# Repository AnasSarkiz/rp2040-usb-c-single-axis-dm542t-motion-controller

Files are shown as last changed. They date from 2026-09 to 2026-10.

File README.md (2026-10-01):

# RP2040 USB-C Single-Axis Stepper Motion Controller for External DM542T Drivers with STEP/DIR/ENABLE Outputs and Dual Limit-Switch Inputs

**Revision A0 — untested prototype. Four-layer candidate fails routing validation. Not fabrication ready; do not order the historical exports.**

USB-C powers an RP2040 and connects a computer to one external STEPPERONLINE DM542T V4.0. The external driver supplies motor current from its own supply. This board carries control signals only. The public package includes circuit sources, the complete sourcing BOM, firmware sources and tests. Detailed investigation artifacts and compiled firmware remain local. The prototype.13 audit missed two via-to-via copper clearance violations. The current four-layer layout remains under routing review. Native routing and independent copper audits must both pass before fabrication; see the exact current results in VALIDATION.md. Historical manufacturing exports are retained for traceability and are not approved for ordering. See [VALIDATION.md](VALIDATION.md).

All 85 fitted components have exact JLCPCB mappings in [BOM.md](BOM.md) and [bom.csv](bom.csv). These are sourced parts, not an approved assembly package.

Research update, 2026-10-01: the requested USB-C-powered onboard-driver redesign is based on the reviewed PD-Stepper reference, targeting a TMC2209 and STEPPERONLINE 17HS08-1004S motor at 15 V nominal. This is a design proposal, not the circuit currently published here. The JLCPCB-only review found a defective C55266 import, so the previous schematic/placement approvals are withdrawn. See the reference decision in [DESIGN-REVIEW.md](DESIGN-REVIEW.md) and the blocker in [VALIDATION.md](VALIDATION.md). Do not apply 15 V to the existing A0 board.

## Wiring for the selected driver

Target: **DM542T V4.0, manual revision 4.0, October 2020**. Set the driver's **S2 input-voltage selector to 5 V** before connecting it. The factory 24 V setting is incompatible with this controller. No compatibility claim is made for another DM542T revision or similarly named driver.

```text
Computer ── USB-C data + 5 V ── Controller A0
                                  J2 pin 1 VDRV ─── PUL+
                                  J2 pin 2 sink ─ PUL−
                                  J3 pin 1 VDRV ─── DIR+
                                  J3 pin 2 sink ─ DIR−
                                  J4 pin 1 VDRV ─── ENA+
                                  J4 pin 2 sink ─ ENA−
                                                   DM542T ── Motor
                                                      │
                                               Separate motor supply
```

Use a twisted pair for each +/− control pair. Do not connect the motor supply to this PCB. The controller and driver control inputs use the driver's optical isolation; no additional motor-power ground connection is required for these pairs. VDRV connector pins are outputs, not external power inputs. Backfeeding any test pad or connector is outside the design's supported use.

| Connector | Pin 1 | Pin 2 | Location/order in top view |
|---|---|---|---|
| J1 | USB-C receptacle | — | Left edge, USB 2.0 data wiring; RP2040 operates at full speed |
| J2 | PUL+ / VDRV (4.75 V) | PUL− / switched sink | Upper edge; left −, right + |
| J3 | DIR+ / VDRV (4.75 V) | DIR− / switched sink | Upper edge; left −, right + |
| J4 | ENA+ / VDRV (4.75 V) | ENA− / switched sink | Upper edge; left −, right + |
| J5 | MIN dry-contact input | GND | Lower edge; left MIN, right GND |
| J6 | MAX dry-contact input | GND | Lower edge; left MAX, right GND |

The MOSFET interface is common-anode. STEP uses two series switches, controlled by STEP and ARM, with hardware pulldowns. GPIOs do not directly drive the driver optocouplers. See [DESIGN-REVIEW.md](DESIGN-REVIEW.md) for calculations and power budgets.

## Enable and fault behavior

The selected driver's ENA input **disables** its output when energized. Q4 defaults on while the switched 4.75 V driver rail exists. That rail stays off during reset, flashing, pre-configuration and USB suspend; in those states the driver may hold torque, while STEP remains gated off. An explicit `ENABLE` command makes Q5 turn Q4 off; firmware then waits 200 ms before accepting motion. STEP stays off until a move is commanded. DIR is held through each pulse and changes before a guarded move.

| State | STEP behavior | Driver behavior intended by this revision |
|---|---|---|
| Reset / bootloader / unconfigured / suspend | STEP and ARM gate pulldowns | Driver rail off; ENA released, holding torque possible |
| Configured, rail ready, before ENABLE | STEP and ARM low | ENA energized: disabled |
| ENABLE, settling | No pulses for at least 200 ms | ENA released: enabled |
| Commanded motion | PIO pulses; ARM asserted | Enabled |
| STOP, motion fault or DTR drop with VDRV present | Planner abort and ARM low | ENA energized: disabled |
| No heartbeat for 1 s | Abort and invalidate homing | Disabled while controller supply remains valid |
| Overload, USB reset or loss of controller power | No sustained STEP drive | **ENA loses current; driver may remain enabled and hold torque** |

The TPS3839 supervisor resets the MCU on 3V3 brownout; the firmware ADC monitors upstream power separately. Startup, shutdown, brownout and bootloader pulse suppression still require oscilloscope evidence. This board is not a safety-rated torque-off circuit.

## Limit switches and homing

Wire **normally-closed, dry-contact** switches between each input and its GND terminal. A switch opening or a broken/disconnected wire asserts that limit. Unused inputs must be intentionally closed to GND for bench use; removing this protection from a real axis is not the default setup. Do not attach 24 V industrial sensors.

Each input has a 1 kΩ series resistor, 10 kΩ pullup, 100 nF filter and ESD clamp. Both asserted limits fault. Motion toward an asserted limit is rejected; movement away is allowed. Homing releases an initially active MIN switch, seeks MIN, backs off, then slowly relatches and zeros the commanded position. Each phase has time and travel bounds; a permanently open wire cannot complete the release step. See [firmware/README.md](firmware/README.md).

## Programming, controls and test pads

Hold BOOTSEL (SW1), press/release RESET (SW2), then release BOOTSEL to enter the ROM USB loader. Firmware builds to ELF/BIN/HEX and can be loaded with official picotool or an SWD probe. The firmware guide contains the tested build environment, commands and a host movement example. No firmware has been flashed to physical hardware in this task.

TP1 V5; TP2 3V3; TP3 1V1; TP4 GND; TP5 STEP; TP6 DIR; TP7 ENABLE; TP8 ARM; TP9 SWCLK; TP10 SWDIO; TP11 RUN. Bare pads are 1.4 mm diameter. LED1 indicates the 3.3 V rail; LED2 indicates the firmware-enabled state. Position counts commanded pulses, without encoder feedback.

The driver supply starts only after USB configuration. Allow 40 ms for its startup; an overload latches it off until USB reconnection. Use a USB data port supporting the requested 500 mA. Intended indoor range is 0–50 °C and control-pair loop resistance must be ≤1 Ω. These limits are design targets pending measurement.

Firmware supports signed relative moves, configurable speed/acceleration, ENABLE/DISABLE/STOP, homing, status and heartbeat. Intended maximum is 2000 steps/s with 10 µs high pulses. Software tests and compilation pass; loaded output timing and motor performance have not been measured.

## Mechanical design

The user authorized a new outline and mounting pattern on 2026-09-28, replacing the original matching requirement. Board: 90 × 60 mm, nominal 1.0 mm FR-4, four copper layers proposed, top-side assembly. Four 3.2 mm finished NPTH holes have centers (5,5), (85,5), (85,55), (5,55) mm from the lower-left corner: 80 × 50 mm spacing. Native 4.03 mm-radius keepouts reserve at least the 8 mm hardware envelope after polygon approximation. M3 hardware must fit that envelope. No existing enclosure fit is claimed; screw head, standoff, cable and terminal screwdriver access require prototype review.

PCB identity text is exactly:

- RP2040 USB-C Motion Controller
- Single Axis • STEP/DIR/ENA • Dual Limits
- REV A0

The exact product name is also in project metadata and the prototype [store listing](STORE-LISTING.md).

## Reproduce and review

Run board commands from this directory only. Use Bun 1.3.9 and `bun install --frozen-lockfile`, then `bun run format:check`, `bun run typecheck`, `bun run bom`, and `bun run test:firmware`. `bun run test:placement` checks an unrouted placement build. `bun run test:board` checks routed connectivity and rejects emitted PCB errors. Full staged tscircuit commands and their actual results are in [VALIDATION.md](VALIDATION.md). `dist/index/pcb.png` is a routed design render, not a photograph or physical-test result.

USB suspend handling, regulated driver power and overload monitoring are implemented. Routed-copper checks are being repeated with expanded via-spacing coverage. Final fabrication review and all physical measurements remain pending. Gerbers, drills and an 85-part placement file are included for review; they are not approved for ordering. No fabrication order has been placed. Use [BRING-UP.md](BRING-UP.md) after all pre-fabrication gates pass.

Storage recovered on 2026-09-29. The earlier corrupted output remains quarantined locally; complete rejected candidates are preserved as historical evidence. Current source is a rejected four-layer candidate. Earlier rejected routes remain historical evidence. Prototype.13 had no detected opens or shorts, but its via copper spacing fails the expanded audit.

## Repositories and versions

Source version **0.1.0-prototype.19**, hardware revision **A0**. Public source publication was authorized on 2026-09-29; it does not approve fabrication or hardware operation.

- [GitHub repository](https://github.com/AnasSarkiz/rp2040-usb-c-single-axis-dm542t-motion-controller)
- [tscircuit project](https://tscircuit.com/AnasSarkiz/rp2040-usb-c-single-axis-dm542t-motion-controller--01a0e89c)

Each meaningful saved revision is committed and tagged in GitHub and pushed to tscircuit with the same version. See [VERSIONING.md](VERSIONING.md). Historical manifests and rejected routing artifacts predate Git history and remain in the local investigation archive; they are not reconstructed or relabeled as validated releases. Public check results and hashes are in [evidence/public-validation.json](evidence/public-validation.json). Local toolchains, downloaded manufacturer PDFs, private task input and corrupted output are excluded from publication.

The independent physical-connectivity audit requires Shapely 2.1.2 (`python3 -m venv firmware/.venv`, then `firmware/.venv/bin/pip install shapely==2.1.2`). Run `bun run test:connectivity` after routing. Prototype.3 passed native DRC and shorts but this additional audit found an open VBUS_SENSE connection. Prototype.10 resolved that open and passed the checks available then; the later via-spacing audit invalidates its clearance acceptance. The labels were cleaned up in prototype.11. Prototype.12 fixed the terminal stencil output and bullet glyphs. Prototype.13 adds readable per-chip schematic notes. Prototype.14 withdraws its clearance pass after finding two via copper gaps below the design rule, adds permanent regression checks, and assesses a four-layer layout. The four-layer route fails validation and is not ready to manufacture.

## Current preview and manufacturing review

The schematic uses eight native A4 landscape sheets (297 × 210 mm): MCU/decoupling, USB, logic power, flash/clock, reset/debug, driver power, motion outputs and limit inputs. Each IC has nearby function and rating notes. All eight PDF pages were inspected; the automated sheet check also verifies the original 273 required pin-to-net mappings.

[Eight-page A4 schematic PDF](dist/index/schematic-a4.pdf) · [First schematic sheet](dist/index/schematic-sheet-1.svg) · [Current validation record](VALIDATION.md).

**Routing under review — these are design renders, not physical photographs or fabrication approval.**

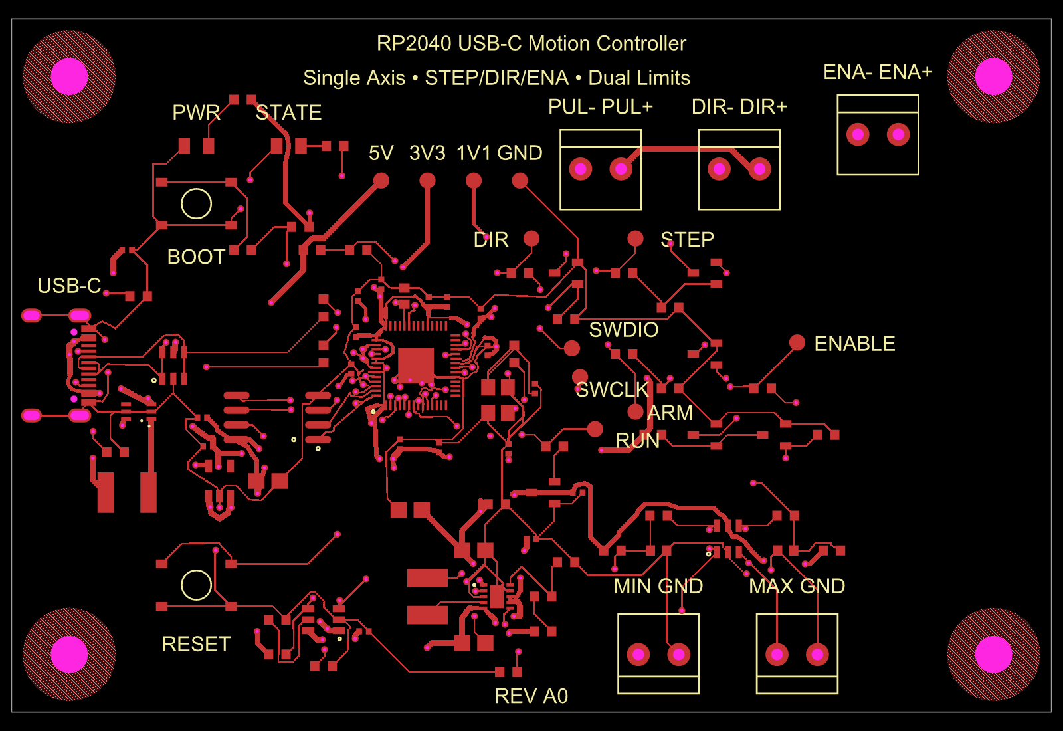
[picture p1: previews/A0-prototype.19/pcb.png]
A0 four-layer routing candidate


[Inner ground layer](previews/A0-prototype.19/inner1.svg). No prototype.19 manufacturing export is approved. Historical exports remain withdrawn from ordering.

## Cloud build timeout

Source release `0.1.0-prototype.17` sets `build.workerTimeoutMs` to `3600000` (60 minutes) in `tscircuit.config.json`. The prototype.14 cloud worker was terminated at its previous 600000 ms limit while routing was still advancing. An environment-level `TSCIRCUIT_BUILD_WORKER_TIMEOUT_MS` overrides this config if the host sets one; the host may also impose a separate overall deadline. Prototype.16 registry metadata reports `user_code_job_timeout` with “Build timed out after 30 minutes”, indicating an overall hosted-job deadline. Increasing the worker setting does not establish that this platform deadline has changed. Hosted completion with the increased limit remains unverified. That timeout change did not validate copper. The current prototype.19 has additional source, placement and dependency changes and its own validation results.

## Bottom evaluation notice

Source release `0.1.0-prototype.16` adds “For evaluation only; not FCC approved for resale.” to the bottom silkscreen in two centered lines at 1.8 mm font size. The [bottom placement preview](previews/A0-prototype.16/bottom-silkscreen-unrouted.png) is an unrouted render for reviewing the notice, not a fabrication-approved layout. The native layer render uses top-view coordinates, so bottom lettering appears mirrored and reads normally from the underside. The 60-minute build-worker timeout is configured in prototype.17.

## Included local build — prototype.19

This release includes fresh native output under `dist/`, uploaded with `--include-dist`. The eight-page A4 schematic is included. Routed acceptance is reported separately in [build status](dist/build-status.json) and [dist notes](dist/README.md); publication is not fabrication approval. Including dist does not establish that the service skips its cloud rebuild or changes the overall hosted timeout.

Current prototype.19 routing result: **84 native DRC errors**, 29 native shorts findings and three independently shorted net groups. A4 schematic conversion is complete; this source release is rejected for fabrication. See [VALIDATION.md](VALIDATION.md).

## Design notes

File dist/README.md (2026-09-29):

# Rejected routed prototype — 0.1.0-prototype.19 / A0

Do not fabricate. Fresh native output from candidate 19j has 84 DRC errors. The native shorts check reports 29 raster/Gerber findings; the independent connectivity audit finds three shorted net groups. Independent geometry finds three via-pair violations, 13 ordinary drill-to-pad violations and 29 non-GND traces on the reserved inner1 plane. All required ports are joined, but the unintended connections make this result unacceptable.

The eight native A4 landscape schematic sheets and eight-page schematic-a4.pdf are reviewed. Per-sheet SVGs are included because the default schematic.svg is only the first sheet. All 273 required pin/net mappings match prototype.18. PCB previews are diagnostic renders, not fabrication approval or physical photos. Snapshots failed and were not accepted. There is no current approved manufacturing export.

See build-status.json for source/output hashes and validation/ for independent reports. Full candidate history and unresolved router/fanout blockers are in ../VALIDATION.md. The worker timeout remains 60 minutes; hosted overall timeout resolution is unverified.

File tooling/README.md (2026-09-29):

# Source-built fabrication fixes

These four packages are local forks, **not official upstream releases**. They
are installed by the board's locked Bun overrides. The ordinary `tsci` commands
load the board's core package; there is no runtime monkey patch and no Gerber or
Circuit JSON rewriting. Every published package archive is hashed in
`manifest.json`, alongside its official upstream Git commit and source patch.
Upstream licenses are preserved in `licenses/`.

- **props/core:** explicit `solderPasteDisabled` on plated holes. The optional
  boolean leaves existing shape-specific behavior unchanged when omitted or
  false. True omits paste on both sides, while retaining the original copper,
  drill, mask, and connectivity. It does not conflict with mask properties.
  The board sets it only on J2–J6. The core version reporter also returns the
  actual package version, including its local prerelease suffix.
- **core a0.2:** classifies internal component links before expanding net aliases.
  Previously, an internally connected switch pad made every obstacle on its net
  assignable, including fixed ground pads and the unbroken ground plane. The
  change preserves assignable interconnect pads/vias and fixes unrelated copper.
  A failing-before/passing-after regression, reviewed snapshot, 23 related tests,
  typecheck and canonical build validate this source fix. The board SRJ now has a
  fixed ground plane and 10 actual assignable obstacles instead of 80.
- **alphabet:** adds U+2022 BULLET to the stroke alphabet and advance metrics.
  Outlines and the TTF/base64 font are regenerated by the upstream scripts.

Validation: props parsing/default/rejection tests and typecheck pass; core
typecheck, canonical build, version test, and 17 relevant plated-hole/paste
regressions pass; all 10 alphabet tests pass. New visual snapshots were rendered
and inspected. Upstream font generation emits one Boolean-union warning on both
the unchanged baseline and this fork; the added bullet's stroke, polygon, and
TTF exports pass explicit regression checks. DejaVu comparison tests report that
the optional reference font is absent; they are not counted as comparisons.

`python3 scripts/rebuild-tooling.py` reconstructs the source checkouts under
`.tscircuit/rebuild-toolchain/`, applies the source patches, copies the regression
tests, regenerates props docs/font outputs, checks and builds the packages, and
packs them into that folder's `packages/`. It requires network access, Bun 1.3.9,
Python 3.14, the standard `patch` command, and yalc 1.0.0-pre.53. It uses the
handbook's yalc workflow only between source packages. It does not replace the
board's reviewed package archives or publish anything. Inspect any rebuilt
package before updating the manifest and lockfile.

The source fixtures in `regression-tests/` compile and run in their respective
upstream repositories, not as board circuit sources.

Reconstruction verification on 2026-09-29: the helper reconstructed, built and
tested props and alphabet. Core's fresh dependency installation stalled without
network activity and was stopped after more than ten minutes; the helper now
limits this installation to five minutes and fails explicitly on timeout. Thus
end-to-end verification of this convenience helper remains incomplete. The
reviewed core archive was built and typechecked from the same patched source in
the original checkout, where all relevant core tests passed. The board installs
the hashed archives from its locked dependencies without rebuilding them.

**Autorouter a0.2 (prototype.19):** repair-stage DRC carries the board's
`minViaHoleEdgeToViaHoleEdgeClearance` through Circuit JSON conversion as a
floor. The indexed repair engine measures copper edges, so its search margin
subtracts the smallest via annular-diameter difference from the drill rule.
For 0.30/0.60 mm vias, the 0.46 mm drill gap becomes 0.16 mm copper gap;
this conversion stays conservative for mixed via sizes. The authoritative
check still examines actual holes. Nine focused tests, TypeScript and the
canonical build pass. This does not guarantee a route solves.

The source checkout follows upstream's disabled lockfile-saving setting. An
attempt to save a source lockfile produced an invalid unresolved peer entry;
that file is quarantined locally and is not published or used by the helper.
The board's own dependency lockfile and package archive hashes remain the
reproducibility boundary. Source reconstruction has not been verified end to
end. No upstream benchmark was run: the repository requires Blacksmith for
benchmarks, unavailable here.

**Core a0.3 (prototype.19):** the configured `autorouter.traceClearance`
is now forwarded as the local solver's `defaultObstacleMargin`, including
explicit per-phase settings and the legacy simplified remote endpoint. A
regression reproduced the missing 0.23 mm setting and passes with the fix.
The core's 24 focused tests, TypeScript and canonical source build pass.
The board requests 0.20 mm routing clearance; physical acceptance thresholds
remain unchanged. No generated copper is modified.

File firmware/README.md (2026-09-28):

# A0 firmware — compiled, not tested on hardware

RP2040 GPIOs: 0 STEP, 1 DIR, 2 ENABLE, 3 ARM, 4 MIN, 5 MAX, 6 driver input switch, 7 driver converter enable, 8 active-low power fault, 25 status LED, 26 protected-5-V ADC. The 12 MHz crystal feeds a 48 MHz system clock. Flash boot uses SDK `boot2_w25q080`, whose source explicitly supports W25Q16JV. This board uses 2 MiB flash. No Pololu code is reused.

## Build

Tested: Raspberry Pi Pico SDK 2.2.0 (`a1438dff1d38bd9c65dbd693f0e5db4b9ae91779`), TinyUSB `86ad6e56c1700e85f1c5678607a762cfe3aa2f47`, Arm GNU 13.2.Rel1 for macOS arm64, CMake 3.31.6. SDK and TinyUSB licenses remain in `vendor/`. All dependencies are under this board directory. The global Homebrew compiler could not link because `nosys.specs` was missing; use the official Arm distribution.

From the board directory, with the pinned SDK at `firmware/vendor/pico-sdk`:

```sh
firmware/.venv/bin/cmake -S firmware -B firmware/build-arm -DCMAKE_BUILD_TYPE=Release -DPICO_TOOLCHAIN_PATH="$PWD/firmware/vendor/arm-gnu-toolchain-13.2.Rel1-darwin-arm64-arm-none-eabi"
firmware/.venv/bin/cmake --build firmware/build-arm -j 4
bun run test:firmware
```

A standard installation of the same CMake version can replace the local Python-venv executable. A full official Arm installation works; this checkout extracted baseline and Cortex-M0+ libraries only to fit disk space. `scripts/install-arm-toolchain.py` records the exact archive hash and omitted multilib directories in the local `evidence/toolchain-install.json`; the public validation record includes the original archive hash. No compiler or SDK internals were modified. Reconstruct the SDK with `git clone --branch 2.2.0 --depth 1 https://github.com/raspberrypi/pico-sdk firmware/vendor/pico-sdk`, then initialize its `lib/tinyusb` submodule. Retain the recorded commits when reproducing.

Outputs are `build-arm/motion_controller.elf`, `.bin`, and `.hex`. The ELF compiles with `-Wall -Wextra -Werror`; this is software build evidence only. The optional SDK picotool build is disabled, so no UF2 is emitted. With a separately installed official [picotool](https://github.com/raspberrypi/picotool), hold BOOTSEL while pressing RESET, release RESET, then release BOOTSEL. Use `picotool load firmware/build-arm/motion_controller.elf`, then `picotool reboot`. Disconnect the driver while first programming. SWCLK, SWDIO, RUN, 3V3 reference and GND test pads also support an external SWD probe; the probe must not power the board.

## Serial protocol

ASCII, one command per newline; CR is ignored. Open the CDC port with DTR asserted. Baud rate does not set motion timing. Maximum line length is 79 characters. Replies are `OK`, `ERR reason`, or a `STATUS` line. Negative numbers require an ASCII minus sign. Trailing arguments, whitespace, out-of-range values and numeric overflow are rejected.

| Command | Meaning |
|---|---|
| `SPEED 500` | Set 1–2000 steps/s while idle; default 500 |
| `ACCEL 1000` | Set 1–20000 steps/s² while idle; default 1000 |
| `ENABLE` | Release the powered driver's disable input; wait at least 200 ms before a move |
| `MOVE -100` | Relative move, −1,000,000 to +1,000,000 commanded steps |
| `HOME` | Home toward MIN; release if initially open, seek, back off, then latch slowly |
| `PING` | Reset the one-second host heartbeat timer; send at least every 200 ms |
| `STOP` / `DISABLE` | Immediate planner abort; disable and invalidate homing |
| `STATUS` | Position, enable, homed, numeric mode, limits, supply-valid and fault |

Mode values: 0 idle, 1 moving, 2 initial home release, 3 seek, 4 backoff, 5 slow latch. Positive moves use DIR=1 at the MCU; actual motor direction depends on wiring. Position counts requested pulses and is not encoder feedback. Homing establishes zero only after a stable latch. Each homing phase is bounded by 30 s and 20,000 steps. Seek/release/backoff are at most 300 steps/s; latch at most 100 steps/s. A switch must remain stable for 5 ms to complete a phase. Ordinary directional limits stop on the first sampled assertion. Moving away from a single asserted limit is permitted; two asserted limits fault.

A PIO program drives STEP high for ten 1 µs cycles and low for at least ten cycles. The planner runs every 100 µs, ramps its pulse rate, and adds a 2 ms direction guard. At the 2000 steps/s cap, normal rising edges are at least 500 µs apart. PIO FIFO backlog or timer intervals outside 90–150 µs abort motion. USB arrival timing never directly generates a pulse. These timing calculations are not oscilloscope measurements; interrupt execution time, MOSFET edges and loaded optocoupler current remain physical tests.

Disconnect, missing heartbeat, undervoltage, both limits, homing timeout and STOP disarm STEP. The 500 mA USB configuration keeps driver power off before enumeration; the input switch starts first, the converter after 20 ms, and readiness after 40 ms. V5 ADC threshold 2600 is nominally 4.19 V. The TPS3839 handles 3V3 brownout independently. A driver overcurrent fault latches its supply off until USB reset/unmount; suspend does not clear this latch.

Suspend aborts motion, turns driver power off, stops/clears PIO and the planner timer, disables ADC/watchdog and waits in deep sleep with USB clocks retained. System clock drops to 12 MHz, then restores to 48 MHz on resume. Old commands and pulses are cleared; re-enable explicitly. ENA loses optocoupler current while driver power is off, so holding torque can return. USB suspend current, reset pulse suppression and all loaded timing need physical measurement.

`bun run test:power` tests sequencing, undervoltage, suspend/resume, timer wrap and overload latching with sanitizers. `bun run test:firmware` tests parsing and motion. Cross-compilation and these tests do not establish hardware behavior.

## Host example

Install `pyserial==3.5` in a task-local virtual environment. With both normally-closed limits wired, axis clear, and the driver configured per the board README:

```sh
python firmware/host-example.py /dev/cu.usbmodemXXXX --steps 100
```

This explicitly moves the axis, polls status, sends heartbeat messages, and stops afterward. The example has not been run against physical hardware. Use a physical machine stop independent of USB software where the machinery requires one.

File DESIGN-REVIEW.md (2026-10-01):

# A0 engineering review

Historical A0 review, 2026-09-29. Its placement/routing approval is withdrawn by the 2026-10-01 JLCPCB-only import audit; see VALIDATION.md. The reference-led redesign below is a proposal, not an implemented circuit. Physical performance remains unverified. Calculations below are design allocations, not measurements. See VALIDATION.md for the separate routing, fabrication and physical-test gates.

## References and selected driver

The [official DM542T V4.0 manual](https://www.omc-stepperonline.com/download/DM542T_V4.0.pdf), revision 4.0 / October 2020, specifies 7–16 mA input current, 4.5–5 V high for the 5 V setting, 0–0.5 V low, ≥2.5 µs pulse high and low, ≥5 µs direction setup and 200 ms enable lead. Set S2 to **5 V**; its factory setting is 24 V. Energizing ENA disables the output; opening ENA enables it. Loss of control power can restore holding torque. No additional numeric DIR hold requirement was found; firmware holds direction through each pulse and provides a 2 ms reversal guard.

The [RP2040 hardware guide](https://datasheets.raspberrypi.com/rp2040/hardware_design_with_rp2040.pdf), [datasheet](https://datasheets.raspberrypi.com/rp2040/rp2040-datasheet.pdf) and [minimal reference CAD](https://datasheets.raspberrypi.com/rp2040/Minimal-KiCAD.zip) supply the reference topology. Retrieved minimal CAD is R3-S1 / July 2026; its MIT license is preserved in references/Minimal-KiCAD-LICENSE.txt. The PCB layout is original. The [Pololu Tic T249](https://www.pololu.com/product/3139) informed command/status usability; no Pololu firmware or CAD is reused.

## MCU, USB and reset

All six RP2040 IOVDD pins, ADC_AVDD, USB_VDD and VREG_IN connect to 3V3. VREG_OUT feeds both DVDD pins; TESTEN and exposed pad 57 are grounded. Unused GPIOs are explicitly unconnected. One-microfarad regulator capacitors and local 100 nF bypasses follow the reference; actual loop lengths and return paths must pass routed review. GPIO0/1/2/3 drive STEP/DIR/ENABLE/ARM, 4/5 read MIN/MAX, 6/7 sequence driver power, 8 reads its fault, 25 drives status and 26 reads protected V5.

W25Q16JVSSIQ is the **208-mil SOIC-8**, not the narrow package. Pins 1 CS, 2 DO, 3 WP, 4 GND, 5 DI, 6 CLK, 7 HOLD and 8 VCC map to QSPI. Pico SDK 2.2.0 boot2_w25q080 explicitly supports W25Q16JV; divider 4 is selected. ABM8-272-T3 is 12 MHz / 10 pF load. Two 15 pF capacitors give 7.5 pF series equivalent plus parasitics; XOUT uses 1 kΩ damping. Physical oscillator startup and USB timing remain bring-up tests.

[AP2112K-3.3](https://www.diodes.com/assets/Datasheets/AP2112.pdf) VIN and EN connect to V5, output to 3V3, NC unused. C2 is 1 µF/25 V and C3 is 2.2 µF/25 V X7R, increasing output-capacitance margin over the 1 µF recommendation. Local 100 nF bypasses supplement this. At an allocated 75 mA MCU/flash load, (5.25−3.3)×0.075 = 0.146 W; using 184 °C/W gives about 27 °C rise. Indoor design range is 0–50 °C; actual temperature and effective MLCC behavior require measurement.

[TPS3839K33](https://www.ti.com/lit/ds/symlink/tps3839.pdf) monitors 3V3: 2.93 V nominal falling threshold (2.857–2.974 V range), 120–350 ms reset release. Its push-pull output drives RUN through R8=1 kΩ; pressing RESET sinks at most about 3.3 mA, below its ±10 mA absolute rating. This reset forces GPIO high impedance; STEP/ARM pulldowns then break the pulse path. Scope brownout and reset transients before motor operation.

USB-C duplicated power/data contacts are joined, shell is grounded, CC1 and CC2 each have independent 5.1 kΩ pulldowns and SBU is unused. [USBLC6-2SC6](https://www.st.com/resource/en/datasheet/usblc6-2.pdf) protects D+/D−; 27 Ω termination is near the MCU. CC pins terminate only in their pull-downs. The Bourns 500 mA hold fuse protects the upstream path; it is not an active current limiter. [LM66100](https://www.ti.com/lit/ds/symlink/lm66100.pdf) VIN follows the fuse, VOUT feeds V5, CE is tied to VOUT for reverse blocking, ST/GND grounded, NC unused. Power injection through test pads, signal terminals or USB data is unsupported.

TS-1187A switch drawing was inspected: imported pins 1/2 form one internal pair and 3/4 the other. Both pairs are wired explicitly. BOOTSEL pulls flash CS through 1 kΩ; RESET pulls RUN to ground.

## Driver supply and output margins

[TPS63030](https://www.ti.com/lit/ds/symlink/tps63030.pdf) provides **4.75 V nominal VDRV**, avoiding raw USB upper/lower-voltage dependence at the driver. PS/SYNC is tied high for forced PWM and its ±1% feedback specification. R26/R27/R28 are 75k/10k/10k, all 0.1%, 25 ppm/°C. L1 is Sunlord SWPA4018S1R5NT, 1.5 µH ±30%, DCR max 39 mΩ, 1.8 A heating rating and 3.35 A saturation rating. The manufacturer's 4018 table and mechanical drawing were visually inspected. Imported pad width gives a larger toe fillet than the example land pattern; its pad height covers the specified terminal dimensions. C21 is 22 µF input, C22/C23 are 22 µF each output, all 25 V X5R; C24 is 100 nF at VINA. These exceed recommended nominal capacitance; effective capacitance/ripple and startup under DC bias remain physical acceptance tests. R31=10k discharges VDRV after shutdown.

[TPS2553DBVR](https://www.ti.com/lit/ds/symlink/tps2553.pdf), SLVS841F, limits the switched driver branch. Pins: 1 IN=V5, 2 GND, 3 EN=GPIO6, 4 open-drain /FAULT=GPIO8 with 10k pull-up to 3V3, 5 ILIM=100k to GND, 6 OUT=DRIVER_VIN. Section 9.5.1 equations with 1% R32 give approximately **232–306 mA** branch limiting. The internal switch controls inrush; firmware delays converter enable by 20 ms and readiness by another 20 ms. /FAULT after startup latches this rail off until USB unmount/reset. Hardware limiting operates during startup and independently of firmware. EN pulldowns hold both supply stages off during reset and bootloader operation.

Five [AO3400A](https://www.aosmd.com/sites/default/files/res/datasheets/AO3400A.pdf) N-MOSFETs provide current sinks: pin 1 gate, 2 source, 3 drain. RDS(on) max 48 mΩ at 2.5 V gives 1.54 mV at 16 mA through the two series STEP/ARM switches. Gate divider 100 Ω / 10k gives 3.267 V nominal. DIR uses one switch. Q4 defaults on when VDRV exists; GPIO ENABLE turns Q5 on to pull Q4's gate low and release ENA. R17=100k consumes only 47.5 µA when pulled down. No additional series optocoupler resistor is fitted for the selected manual's 5 V connection.

`scripts/power-budget.py` includes feedback tolerance, 0–50 °C drift, 1% line/load reserve, ±25 mV allocated ripple, two FET drops and ≤1 Ω signal-pair loop resistance. Calculated driver-terminal range is **4.599–4.884 V**, within 4.5–5 V. This depends on meeting the ripple/cable allocations; measure them. Converter input must remain ≥4.1 V under load for the stated USB budget. ADC threshold 2600 corresponds nominally to 4.19 V at V5; it detects coarse supply faults, not precise driver voltage.

## USB power and firmware behavior

The descriptor requests **500 mA after configuration**. Driver power stays off before configuration and during suspend. The conservative attachment-capacitance tally, including unswitched downstream capacitors, is 9.35 µF. Pre-configuration current allocation is 80 mA (75 MCU/flash, 5 other), below 100 mA. At 48.5 mA driver load and 70% converter efficiency budget, running allocation is 160.3 mA. Branch limiting plus the 80 mA allocation is at most about 386 mA. Measure actual inrush and current; the 80 mA allocation is not a guaranteed component maximum or a USB certification result.

Suspend aborts motion, drops ARM first, turns off both driver supply stages, clears/disables PIO and timers, disables watchdog/ADC and enters RP2040 deep sleep with USB clocks retained for resume. System clock is reduced to 12 MHz while waiting; unused PLL_SYS is off. Resume flushes commands and requires fresh ENABLE after rail sequencing. TinyUSB USB-reset, suspend and CDC-DTR callbacks also stop motion. SDK USB background polling is disabled using its public configuration, with main-loop USB service. No SDK internals are patched. Suspend current **must be measured below 2.5 mA**; the implementation is not a claim of measured compliance. [USB-IF guidance](https://compliance.usb.org/index.asp?UpdateFile=Electrical).

The SDK-compatible Raspberry Pi CDC VID/PID uses custom manufacturer/product strings and unique flash ID serial, following [Raspberry Pi's USB identifier guidance](https://www.raspberrypi.com/documentation/microcontrollers/microcontroller-chips.html#usb-identifiers). No private PID allocation is claimed.

## Limits, timing and sourcing

NC dry contacts give approximately 0.30 V closed and 3.3 V open, with about 1 ms opening / 91 µs closing RC constants. USBLC6 ESD protection does not support sustained 24 V. Broken wires assert the corresponding limit; two asserted limits fault. Homing requires stable transitions, bounded travel and time. PIO generates 10 µs high/low minimums, the planner caps 2000 steps/s, direction guard is 2 ms and enable lead is ≥200 ms. Software tests exercise these states; physical pulse suppression and loaded timing are untested.

All **85 fitted components** have exact manufacturer/package/JLC mappings and positive assembly-eligible quantities checked in official JLC listings, with individual UTC dates in `bom.csv`. Catalog imports remain unchanged; local wrappers correct the TPS2553 schematic classification and add missing MOSFET reference labels without altering supplier pads. The KF350 terminal footprint follows its drawing (3.5 mm pitch, 1 mm holes, 6.9 mm depth, 8.8 mm height). Top-bank wire entry points upward; lower-bank entry downward. Allow 5 mm underside clearance for leads. Manual-weld terminal assembly must be confirmed at quote review.

JLC planning target: 90×60×1 mm, two-layer FR-4, 1 oz outer copper, ≥0.15 mm signal/clearance, 0.4/0.5 mm power trunks, ≥0.3/0.6 mm via drill/pad, ≥0.5 mm copper-edge clearance. No controlled-impedance claim. Actual copper, ground return, drill clearance, power necks, mask/paste and assembler review are later gates. Mounting and connector access have been visually reviewed; physical enclosure fit remains untested.

## Schematic review annotations (prototype.13)

Every IC U1–U9 has adjacent `schematictext` describing its role and relevant
operating point or rating. Notes distinguish the board's design budgets from
component ratings and from physical measurements. USB protection, reverse
blocking, the 3.3 V regulator, boot/reset controls and flash are separated in
the schematic to keep symbols, labels and the notes clear of wires.

The added flash supply range is 2.7–3.6 V ([Winbond W25Q16JV family](https://www.winbond.com/hq/product/code-storage-flash/qspi-nor/w25q-jv/?__locale=en&partNo=W25Q16JVBYIQ)); the fitted part remains W25Q16JVSSIQ. The 600 mA AP2112 rating is an IC rating ([Diodes](https://www.diodes.com/part/view/AP2112)), not permission to exceed the USB or thermal budget. The 1.5 A LM66100 rating ([TI](https://www.ti.com/product/LM66100)) likewise does not increase the board limit. The TPS63030 input range is 1.8–5.5 V ([TI](https://www.ti.com/product/TPS63030)); the board's required input and driver-current budget remain as documented above. References checked 2026-09-29. Other notes use the established design calculations and datasheets above.

U1 and U7 use increased schematic pin spacing, with enough box width for their pin names. The USB footprint explicitly declares entry from its local negative-Y face, which rotates to the left board edge; this corrects model inference without changing copper or the connector position.

## Combined controller/driver reference decision — 2026-10-01

The user delegated reference and motor selection. Continue in this project; do not represent the existing DM542T controller as an onboard motor driver. No A1 circuit or manufacturing release has been implemented at this checkpoint.

Primary reference: [joshr120/PD-Stepper](https://github.com/joshr120/PD-Stepper/tree/3c40073a0ec51653f6ea48c70f365bd7f9f3bdcc), schematic V1.1. Its [schematic](https://github.com/joshr120/PD-Stepper/blob/3c40073a0ec51653f6ea48c70f365bd7f9f3bdcc/PCB/PD%20Stepper%20V1.1%20Schematic.pdf) was downloaded, rendered and visually reviewed. It combines an ESP32-S3, TMC2209, CH224K and 3.3 V converter on four layers. GPL-3.0 license was reviewed; no CAD, firmware or routing has been copied. Our adaptation retains the RP2040 and two normally-closed limit inputs; its electrical and thermal performance will need independent validation.

Selected reference motor: [STEPPERONLINE 17HS08-1004S](https://www.omc-stepperonline.com/nema-17-bipolar-1-8deg-16ncm-22-6oz-in-1a-3-7v-42x42x20mm-4-wires-17hs08-1004s), four-wire bipolar NEMA 17, 1 A/phase, 3.7 ohms/phase, 4.5 mH and 0.16 Nm holding torque according to the English product page and [manufacturer drawing](https://www.omc-stepperonline.com/download/17HS08-1004S.pdf), checked 2026-10-01. Pair black/green as winding A and red/blue as B, checking continuity before connection. This selection is a bench reference, not a guarantee of suitability for an unspecified mechanical load. Supplier stock was listed when checked; recheck before ordering.

| Design choice | Implementation requirement |
|---|---|
| Motor power | Fixed 15 V nominal USB-C PD request; charger must explicitly offer 15 V at at least 2 A. Never request 20 V in this adaptation. |
| Computer interface | Separate USB-C data/logic port, isolated from the motor PD VBUS; prevent backfeed between both ports. |
| Driver | TMC2209-LA, JLCPCB C465949; STEP/DIR plus UART diagnostics/configuration. Use hardware enable pull-up and inhibit the bridge during reset or failed negotiation. |
| Current target | Start with a conservative 0.7 A RMS sinusoidal setting (about 0.99 A peak), subject to sense/reference tolerances. Do not claim the IC headline current as a board rating. |
| Power negotiation | CH224K, C970725. Hardware straps must request the chosen voltage independently of firmware startup timing. Validate PG behavior and rail voltage before enabling motion. |
| Mechanics | Retain a separate 90 × 60 mm board and existing four-hole pattern for now; reference motor rear mounting is not adopted. Reassess thickness/stackup and cooling before layout. |
| Schematic | Native A4 sheets with RP2040, logic power/USB, PD/protection, driver and limits separated as needed; each IC needs function/rating text. |

The 15 V request is a nominal operating choice. A strict below-21-V ceiling is **not verified**: charger tolerance, hot-plug and regenerated motor energy require a reviewed protection circuit and measured transient limits. Do not use a TVS nominal voltage as its guaranteed clamp voltage. The input current limit, inrush, reverse-current blocking, brake/clamp energy capacity and capacitor ratings remain design work. A 30 W adapter budget is not a claim of 30 W motor output.

For the chosen motor, two windings continuously carrying 1 A would dissipate approximately 7.4 W at nominal resistance. This is a winding-loss calculation, not total input power or validated thermal performance. Speed/torque at 15 V remains unmeasured; the manufacturer's published 24 V curve must not be relabeled for this design.

The [TMC2209 datasheet, rev. 1.09](https://www.analog.com/media/en/technical-documentation/data-sheets/tmc2209_datasheet_rev1.09.pdf), takes precedence over the reference board: its 5VOUT capacitor recommendation is 2.2–4.7 µF, while the reference schematic shows 0.1 µF. Use the manufacturer requirement in the adaptation. Review the 22 nF charge-pump capacitor, local bulk capacitance, current-sense return paths and exposed-pad cooling before routing. The imported pin25 label `_NEG` represents the datasheet's unused `-` pin; it is not a negative supply. Imported pad29 is the exposed ground pad. These are mapping observations, not a completed component review.

Fresh unmodified imports of C465949, C970725 and RP2040 C2040 were obtained in the isolated audit directory. Import success alone does not pass symbol, land-pattern, mask/paste or assembly validation. WCH's [official CH224 datasheet landing page](https://www.wch-ic.com/downloads/CH224DS1_PDF.html) was located, but the current manufacturer PDF has not yet been retrieved and fully reviewed. Do not finalize the PD circuit using only the third-party reference schematic.

The old TPS2553 C55266 model remains a stage-2 blocker for the existing circuit. It is limited to a 5 V-class branch and must never be carried onto the new 15 V rail. The combined design can retire that branch after a complete replacement power architecture is reviewed; this does not validate the defective import or permit a hand-authored substitute. Other retained components also need fresh unmodified imports before their old custom symbol/footprint overrides can be removed.

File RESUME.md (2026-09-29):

# Resume A0 / 0.1.0-prototype.19

Read AGENTS.md, VERSIONING.md and the final prototype.19 section of VALIDATION.md. User requires an actual component adjustment and reviewed unrouted placement before each routing retry; publish meaningful versions to GitHub and tscircuit with --include-dist.

Eight native A4 landscape sheets and an eight-page A4 PDF are complete, all pages visually reviewed, 96 component assignments and 273 unchanged pin/net mappings verified. Candidate 19j still fails: 84 native errors, 29 native shorts findings, three independent shorted net groups, three via-pair violations, 13 ordinary drill-to-pad violations and 29 reserved inner1 intrusions. No snapshot or current fabrication package is approved. Never order historical exports.

Ten candidate investigations (19a–j) are recorded, including interrupted and pre-routing fanout failures. Current native pipeline9/5x uses the tested source-built core a0.3 and router a0.2. The board requests a 0.20 mm routing margin; actual native input confirms it. Manufacturing minima remain unchanged. Fixes and regressions are in tooling/. Native detailed routing/repair and custom-symbol fanout selector failures remain blockers. Do not replace them with edited generated copper, weaker rules or installed-file patches.

Fresh dist, independent reports, hashes, A4 PDF and all layer previews accompany this rejected source version. Worker timeout remains 60 minutes; hosted 30-minute overall deadline resolution is unverified. Next: reproduce/fix reserved-plane and clearance handling and fanout U4.pin1 resolution, then change relevant placement and revalidate. Exact manufacturer stackup, assembler acceptance and physical tests remain pending. Full candidate evidence and toolchain source checkouts are local under evidence/ and .tscircuit/.

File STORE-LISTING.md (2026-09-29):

# RP2040 USB-C Single-Axis Stepper Motion Controller for External DM542T Drivers with STEP/DIR/ENABLE Outputs and Dual Limit-Switch Inputs

**Prototype source release 0.1.0-prototype.19 — revision A0 — untested. Four-layer routing validation failed; manufacturer acceptance pending. Not approved to order.**

A USB-powered RP2040 controller concept for one external STEPPERONLINE DM542T V4.0 driver, with buffered STEP/DIR/ENABLE signals, two normally-closed dry-contact limit inputs, USB bootloader access, SWD test pads, reset/boot buttons and status LEDs.

The 90 × 60 mm four-layer candidate uses four 3.2 mm NPTH mounting holes on an 80 × 50 mm pattern. Proposed firmware provides signed relative moves, speed, acceleration, stop, enable/disable, homing, heartbeat and status, with a 2000-step/s software cap and hardware-timed 10 µs STEP pulses.

The draft package contains tscircuit sources, an exact 85-component JLCPCB BOM, firmware sources and build instructions, software tests and a bring-up checklist. The power design includes a regulated 4.75 V driver rail, current limiting, brownout reset and USB suspend handling. The earlier routing pass missed via copper-spacing violations and is superseded. Label cleanup, manufacturing exports and function/rating notes for every IC are included. Through-hole stencil output, subtitle bullet rendering and printed legend dimensions are fixed and checked. Historical manufacturing packages are included for traceability and must not be ordered; assembler acceptance and physical testing remain outstanding. Actual USB suspend current remains unmeasured. Rendered views must be labeled renders; there are no physical board photos or measured hardware results.

Use the driver's 5 V input setting. No 24 V sensors or motor supply may connect to this board. Loss of controller power can leave the separately powered driver enabled and holding torque. Other driver revisions have not been validated. Intended limits are not measured operating specifications.

The user authorized GitHub and tscircuit source publication on 2026-09-29. This is a work-in-progress source package; fabrication and a sale-ready store release remain blocked by VALIDATION.md. No price, availability date, safety certification or hardware-tested claim is assigned.

Bottom silkscreen carries the requested notice: “For evaluation only; not FCC approved for resale.”

Prototype.19 adds eight native A4 schematic sheets, an eight-page landscape PDF and per-IC function/rating notes. Local routed dist and exact check results accompany the source. Routing and fabrication acceptance remain blocked; do not fabricate.

Current prototype.19 routing result: **84 native DRC errors**, 29 native shorts findings and three independently shorted net groups. A4 schematic conversion is complete; this source release is rejected for fabrication. See [VALIDATION.md](VALIDATION.md).

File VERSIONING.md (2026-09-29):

# Version history and publishing

The user authorized creating both repositories and pushing every meaningful saved version on 2026-09-29. Use the configured AnasSarkiz accounts. Hardware revision A0 is separate from the source package version.

## First source release

`0.1.0-prototype.1` is the first complete source snapshot published to both services. Git tag: `v0.1.0-prototype.1`. Routing is unresolved and no hardware has been built or tested. This is not an approved fabrication package.

Earlier A0 draft/placement manifests and rejected routing candidates remain historical evidence. Full original source snapshots for those states were not saved, so they cannot honestly be recreated as past Git commits or tscircuit versions. Their original hashes and validation limitations remain in the local investigation archive. Only the concise validation record is exported publicly.

## Every subsequent version

1. Make the board changes inside this task directory. Increment `package.json` version and `project.json` source_version; retain the exact product title. Use increasing `0.1.0-prototype.N` versions until an appropriate milestone changes the base version.
2. Revalidate affected stages and record results in VALIDATION.md. Unresolved failures stay visible. Save evidence without overwriting historical records.
3. Review the diff and included files for credentials, private inputs, generated junk and third-party redistribution. Commit the complete source and record an annotated Git tag `v<package-version>`. Never force-update a published tag.
4. Before committing, generate a fresh routed `dist/index/` from the release sources; archive older output outside dist and inspect the result. Include only reviewed native circuit JSON and rendered PCB/schematic files, plus a build-status record and source/output hashes. For a rejected prototype, disclose all errors in dist/README.md and validation records; including dist does not imply a successful build or fabrication approval. Stage the reviewed dist files explicitly because dist is normally ignored. Never reuse a previous version’s dist after source changes.
5. Push the commit and tag to GitHub. Export that exact tag with `git archive` to a fresh task-local `.tscircuit/publish/<version>/` directory.
6. From the export, use the installed canonical `tsci push index.circuit.tsx --include-dist` (individual file upload; compressed upload exceeded the registry request limit for prototype.12). Do not upload the working directory: this CLI version does not honor .gitignore and would include local toolchains. Git archive contains only reviewed tracked files. Keep version unchanged during upload; if the remote version exists, inspect it before assigning another version.
7. Verify both remotes contain the version and matching authored source. Record the publication receipt locally. Registry processing or successful upload does not mean board DRC passed.

Dependencies and tools are reconstructed using the locked package manifest and firmware guide. Public Git history and registry version history preserve each published snapshot. Raw evidence/logs and reference downloads remain local; public-validation.json carries the check outcomes and artifact hashes. Do not force-push, rewrite history or publish credentials. Ordering remains unauthorized.

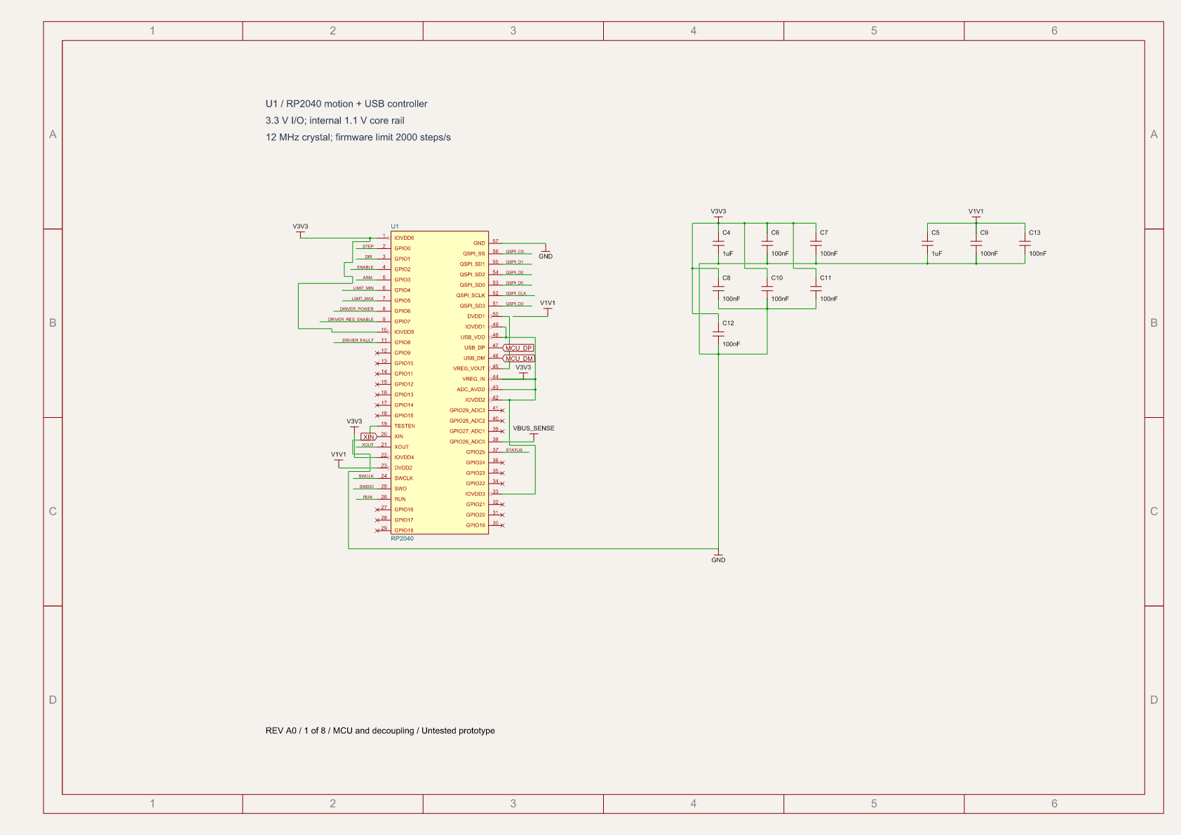
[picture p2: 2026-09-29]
previews/A0-prototype.19/schematic-sheet-1.png

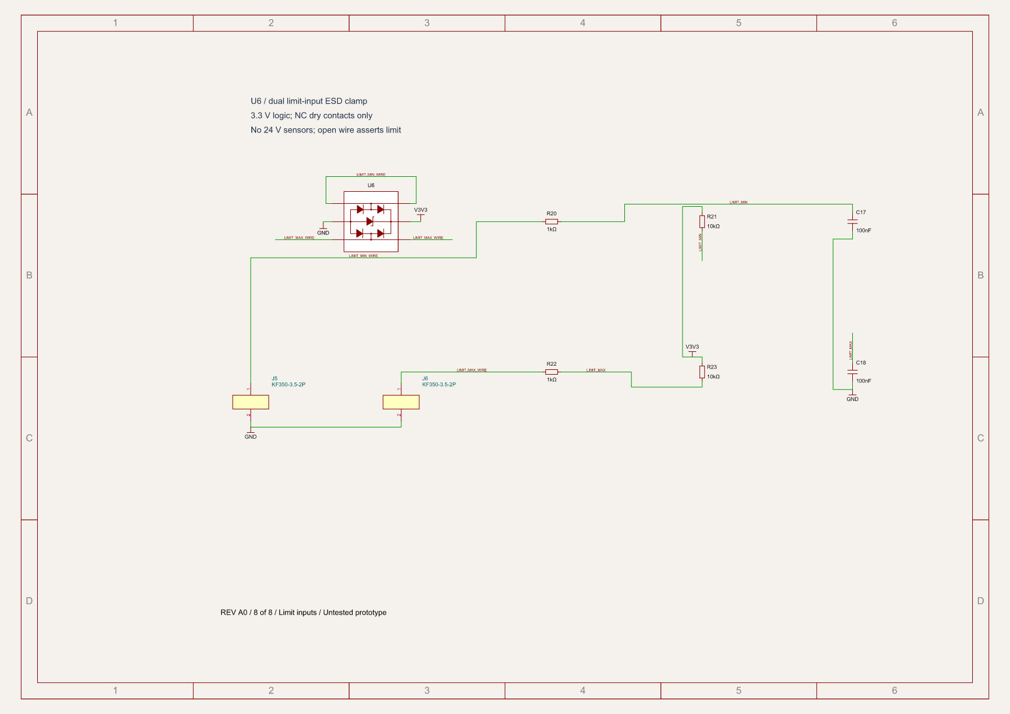
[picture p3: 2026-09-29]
previews/A0-prototype.19/schematic-sheet-8.png

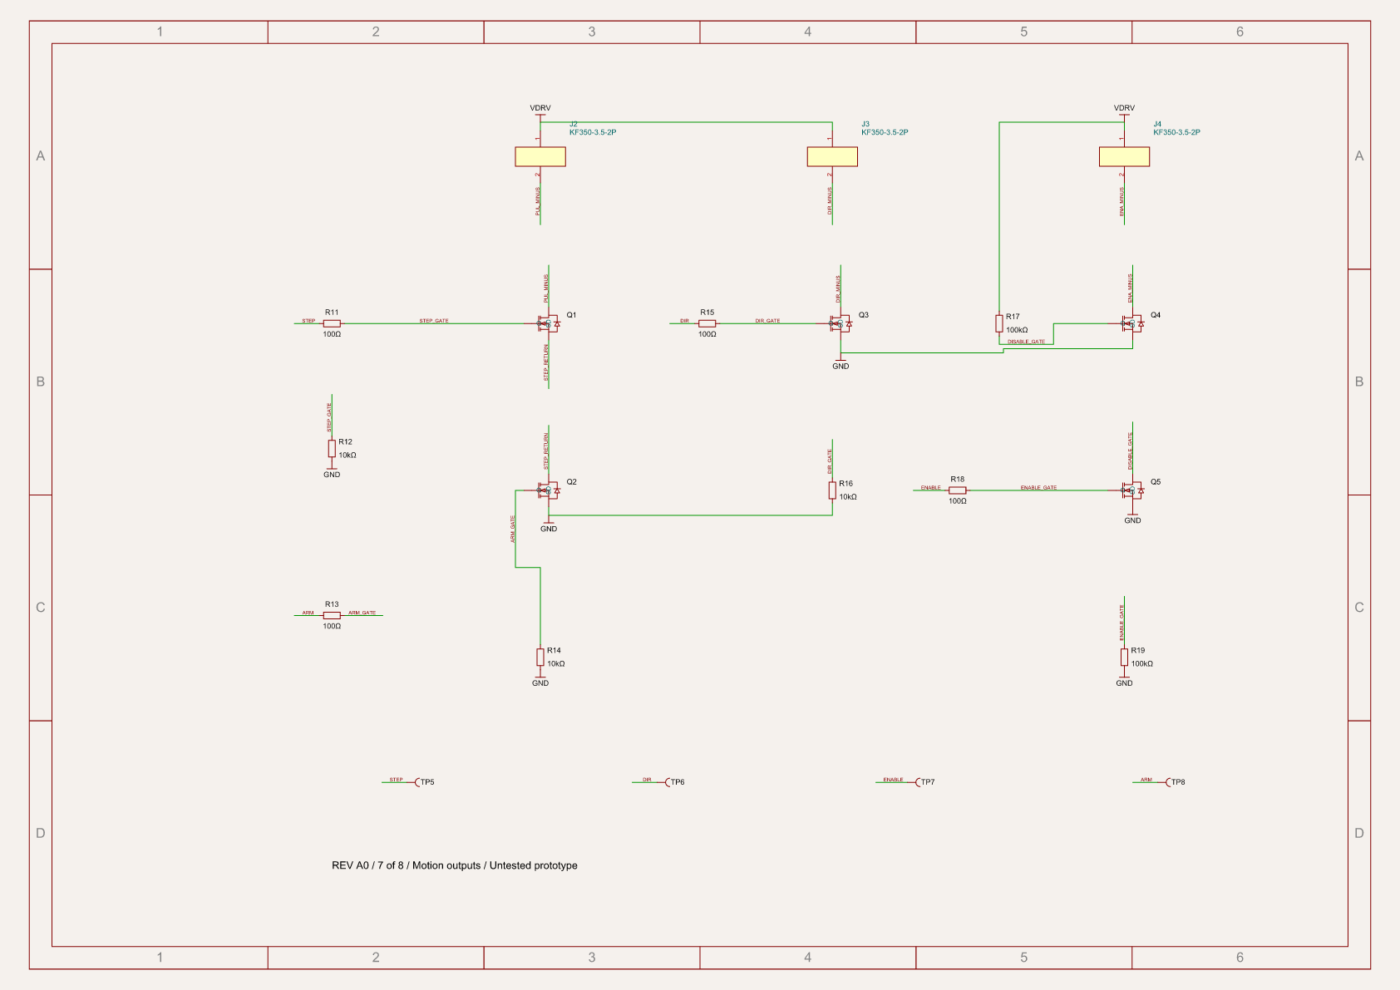
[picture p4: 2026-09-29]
previews/A0-prototype.19/schematic-sheet-7.png

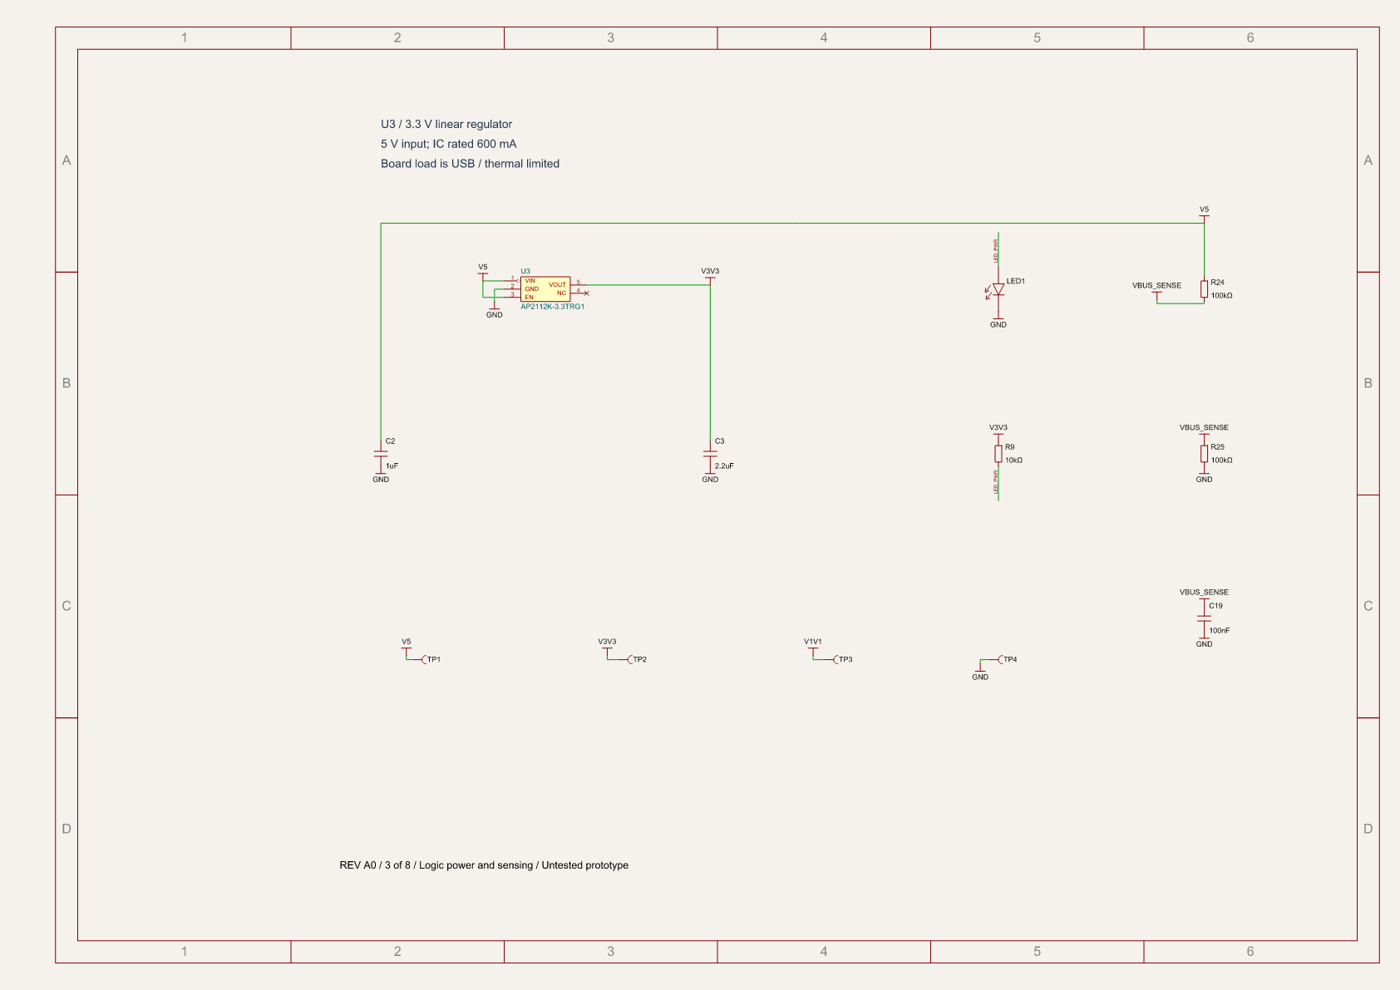
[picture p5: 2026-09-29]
previews/A0-prototype.19/schematic-sheet-3.png

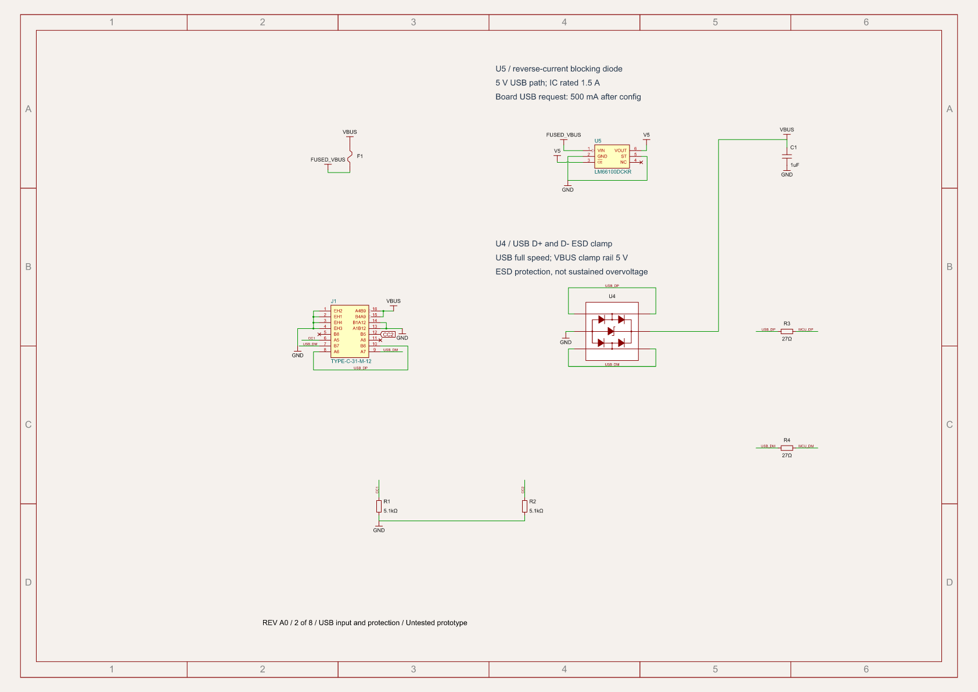
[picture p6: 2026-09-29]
previews/A0-prototype.19/schematic-sheet-2.png

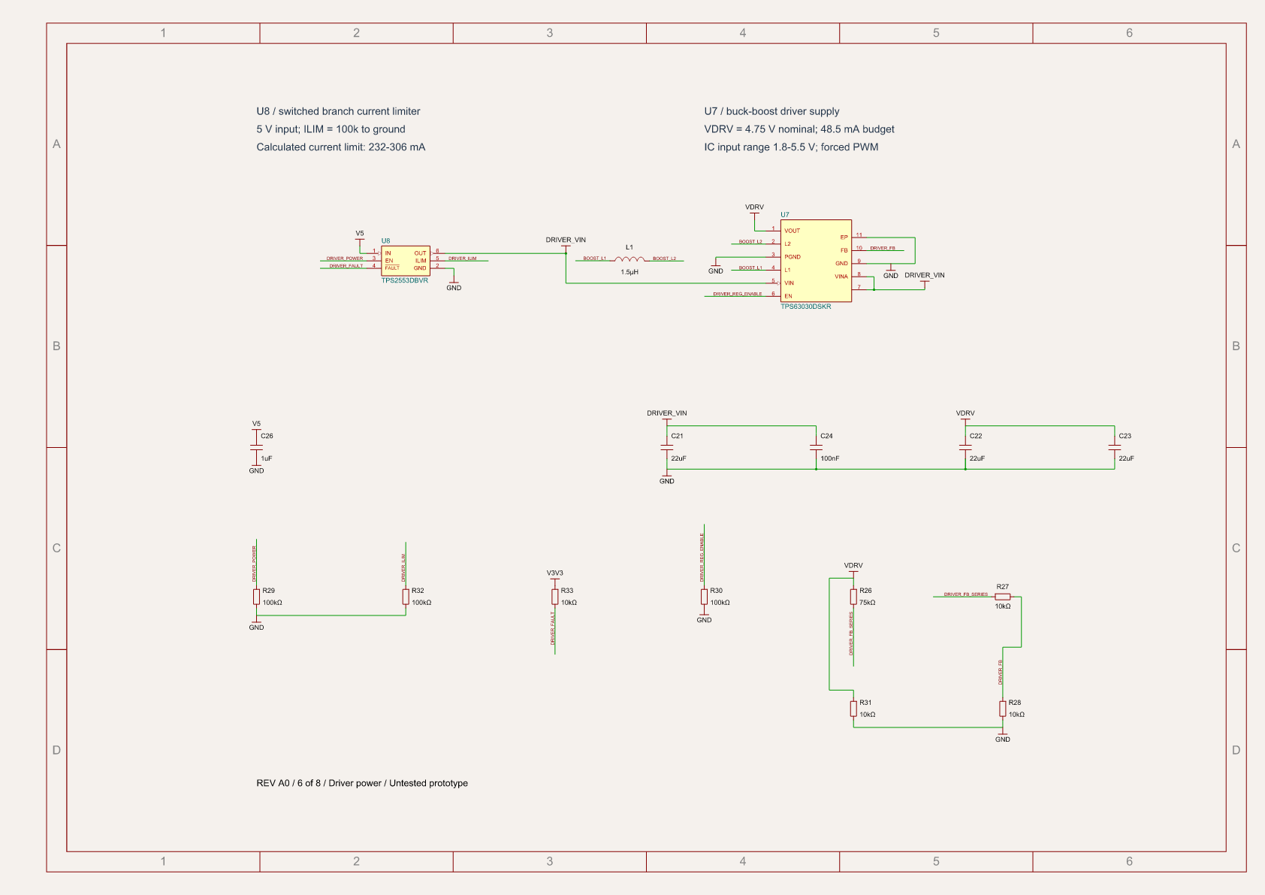
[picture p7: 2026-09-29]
previews/A0-prototype.19/schematic-sheet-6.png

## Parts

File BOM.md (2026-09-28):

# A0 bill of materials

**Untested prototype — schematic reviewed; routed fabrication validation pending.** 85 fitted electronic components. Each row maps to official JLC assembly catalog evidence with individual UTC check dates, stored in references/catalog. Availability is a dated snapshot, not a reservation. Through-hole terminals use manualWeld: confirm Standard PCBA/manual insertion eligibility at quote review.

CSV follows [JLC's BOM field guidance](https://jlcpcb.com/help/article/bill-of-materials-for-pcb-assembly), with extra audit columns. No CPL/assembly upload has been approved.

| Ref | Qty | Function/value | Manufacturer | Full MPN | Package | JLC part | Datasheet | Assembly | Eligible qty | Checked |
|---|---:|---|---|---|---|---|---|---|---:|---|
| U7 | 1 | 4.75 V driver buck-boost regulator | Texas Instruments | TPS63030DSKR | SON-10-EP(2.5x2.5) | [C12462](https://jlcpcb.com/partdetail/C12462) | [PDF](https://www.ti.com/cn/lit/gpn/tps63031) | Extended, smtWeld | 9080 | 2026-09-28 |
| U8 | 1 | Driver branch current-limiting switch | Texas Instruments | TPS2553DBVR | SOT-23-6 | [C55266](https://jlcpcb.com/partdetail/C55266) | [PDF](https://www.ti.com/cn/lit/gpn/tps2553) | Extended, smtWeld | 58665 | 2026-09-28 |
| U9 | 1 | 3.3 V brownout supervisor | Texas Instruments | TPS3839K33DBZR | SOT-23 | [C96333](https://jlcpcb.com/partdetail/C96333) | [PDF](https://www.ti.com/cn/lit/gpn/tps3839) | Extended, smtWeld | 682 | 2026-09-28 |
| L1 | 1 | 1.5 uH buck-boost inductor | Sunlord | SWPA4018S1R5NT | SMD,4x4mm | [C80662](https://jlcpcb.com/partdetail/C80662) | [PDF](https://www.lcsc.com/datasheet/lcsc_datasheet_2310251551_Sunlord-SWPA4018S1R5NT_C80662.pdf) | Extended, smtWeld | 1202 | 2026-09-28 |
| U1 | 1 | RP2040 processor | Raspberry Pi | RP2040 | LQFN-56(7x7) | [C2040](https://jlcpcb.com/partdetail/C2040) | [PDF](https://www.lcsc.com/datasheet/lcsc_datasheet_2201101600_Raspberry-Pi-RP2040_C2040.pdf) | Extended, smtWeld | 67983 | 2026-09-28 |
| U2 | 1 | 16-Mbit boot flash | Winbond Elec | W25Q16JVSSIQ | SOIC-8-208mil | [C131025](https://jlcpcb.com/partdetail/C131025) | [PDF](https://www.lcsc.com/datasheet/lcsc_datasheet_2103181405_Winbond-Elec-W25Q16JVSSIQ_C131025.pdf) | Extended, smtWeld | 12640 | 2026-09-28 |
| U3 | 1 | 3.3 V LDO | Diodes Incorporated | AP2112K-3.3TRG1 | SOT-25-5 | [C51118](https://jlcpcb.com/partdetail/C51118) | [PDF](https://www.lcsc.com/datasheet/lcsc_datasheet_2304140030_Diodes-Incorporated-AP2112K-3-3TRG1_C51118.pdf) | Extended, smtWeld | 39752 | 2026-09-28 |
| U4 | 1 | USB ESD | STMicroelectronics | USBLC6-2SC6 | SOT-23-6L | [C7519](https://jlcpcb.com/partdetail/C7519) | [PDF](https://www.lcsc.com/datasheet/lcsc_datasheet_2410121836_STMicroelectronics-USBLC6-2SC6_C7519.pdf) | Extended, smtWeld | 40780 | 2026-09-28 |
| U5 | 1 | Reverse-current blocker | Texas Instruments | LM66100DCKR | SC-70-6 | [C2869734](https://jlcpcb.com/partdetail/C2869734) | [PDF](https://www.ti.com/cn/lit/ds/symlink/lm66100.pdf) | Extended, smtWeld | 35607 | 2026-09-28 |
| U6 | 1 | Limit input ESD | STMicroelectronics | USBLC6-2SC6 | SOT-23-6L | [C7519](https://jlcpcb.com/partdetail/C7519) | [PDF](https://www.lcsc.com/datasheet/lcsc_datasheet_2410121836_STMicroelectronics-USBLC6-2SC6_C7519.pdf) | Extended, smtWeld | 40780 | 2026-09-28 |
| J1 | 1 | USB-C receptacle | Korean Hroparts Elec | TYPE-C-31-M-12 | SMD | [C165948](https://jlcpcb.com/partdetail/C165948) | [PDF](https://www.lcsc.com/datasheet/lcsc_datasheet_2205251630_Korean-Hroparts-Elec-TYPE-C-31-M-12_C165948.pdf) | Extended, smtWeld | 436119 | 2026-09-28 |
| F1 | 1 | 500 mA hold resettable fuse | BOURNS | MF-MSMF050-2 | 1812 | [C17313](https://jlcpcb.com/partdetail/C17313) | [PDF](https://www.lcsc.com/datasheet/lcsc_datasheet_2410010331_BOURNS-MF-MSMF050-2_C17313.pdf) | Extended, smtWeld | 136466 | 2026-09-28 |
| Y1 | 1 | 12 MHz 10 pF crystal | Abracon LLC | ABM8-272-T3 | SMD3225-4P | [C20625731](https://jlcpcb.com/partdetail/C20625731) | [PDF](https://www.lcsc.com/datasheet/lcsc_datasheet_2410121909_Abracon-LLC-ABM8-272-T3_C20625731.pdf) | Extended, smtWeld | 15051 | 2026-09-28 |
| SW1 | 1 | BOOTSEL | XKB Connection | TS-1187A-B-A-B | SMD-4P,5.1x5.1mm | [C318884](https://jlcpcb.com/partdetail/C318884) | [PDF](https://www.lcsc.com/datasheet/lcsc_datasheet_2304140030_XKB-Connection-TS-1187A-B-A-B_C318884.pdf) | Basic, smtWeld | 499659 | 2026-09-28 |
| SW2 | 1 | RESET | XKB Connection | TS-1187A-B-A-B | SMD-4P,5.1x5.1mm | [C318884](https://jlcpcb.com/partdetail/C318884) | [PDF](https://www.lcsc.com/datasheet/lcsc_datasheet_2304140030_XKB-Connection-TS-1187A-B-A-B_C318884.pdf) | Basic, smtWeld | 499659 | 2026-09-28 |
| LED1 | 1 | Power LED | Hubei KENTO Elec | KT-0805G | 0805 | [C2297](https://jlcpcb.com/partdetail/C2297) | [PDF](https://www.lcsc.com/datasheet/lcsc_datasheet_1806151820_Hubei-KENTO-Elec-KT-0805G_C2297.pdf) | Basic, smtWeld | 965305 | 2026-09-28 |
| LED2 | 1 | Status LED | Hubei KENTO Elec | KT-0805G | 0805 | [C2297](https://jlcpcb.com/partdetail/C2297) | [PDF](https://www.lcsc.com/datasheet/lcsc_datasheet_1806151820_Hubei-KENTO-Elec-KT-0805G_C2297.pdf) | Basic, smtWeld | 965305 | 2026-09-28 |
| Q1 | 1 | Output MOSFET | Alpha & Omega Semicon | AO3400A | SOT-23 | [C20917](https://jlcpcb.com/partdetail/C20917) | [PDF](https://www.lcsc.com/datasheet/lcsc_datasheet_1811081213_Alpha---Omega-Semicon-AO3400A_C20917.pdf) | Basic, smtWeld | 904904 | 2026-09-28 |
| Q2 | 1 | Output MOSFET | Alpha & Omega Semicon | AO3400A | SOT-23 | [C20917](https://jlcpcb.com/partdetail/C20917) | [PDF](https://www.lcsc.com/datasheet/lcsc_datasheet_1811081213_Alpha---Omega-Semicon-AO3400A_C20917.pdf) | Basic, smtWeld | 904904 | 2026-09-28 |
| Q3 | 1 | Output MOSFET | Alpha & Omega Semicon | AO3400A | SOT-23 | [C20917](https://jlcpcb.com/partdetail/C20917) | [PDF](https://www.lcsc.com/datasheet/lcsc_datasheet_1811081213_Alpha---Omega-Semicon-AO3400A_C20917.pdf) | Basic, smtWeld | 904904 | 2026-09-28 |
| Q4 | 1 | Output MOSFET | Alpha & Omega Semicon | AO3400A | SOT-23 | [C20917](https://jlcpcb.com/partdetail/C20917) | [PDF](https://www.lcsc.com/datasheet/lcsc_datasheet_1811081213_Alpha---Omega-Semicon-AO3400A_C20917.pdf) | Basic, smtWeld | 904904 | 2026-09-28 |
| Q5 | 1 | Output MOSFET | Alpha & Omega Semicon | AO3400A | SOT-23 | [C20917](https://jlcpcb.com/partdetail/C20917) | [PDF](https://www.lcsc.com/datasheet/lcsc_datasheet_1811081213_Alpha---Omega-Semicon-AO3400A_C20917.pdf) | Basic, smtWeld | 904904 | 2026-09-28 |
| J2 | 1 | 3.5 mm pitch 2-pole screw terminal | Cixi Kefa Elec | KF350-3.5-2P | Plugin,P=3.5mm | [C474892](https://jlcpcb.com/partdetail/C474892) | [PDF](https://www.lcsc.com/datasheet/lcsc_datasheet_2303171000_Cixi-Kefa-Elec-KF350-3-5-2P_C474892.pdf) | Extended, manualWeld | 6873 | 2026-09-28 |
| J3 | 1 | 3.5 mm pitch 2-pole screw terminal | Cixi Kefa Elec | KF350-3.5-2P | Plugin,P=3.5mm | [C474892](https://jlcpcb.com/partdetail/C474892) | [PDF](https://www.lcsc.com/datasheet/lcsc_datasheet_2303171000_Cixi-Kefa-Elec-KF350-3-5-2P_C474892.pdf) | Extended, manualWeld | 6873 | 2026-09-28 |
| J4 | 1 | 3.5 mm pitch 2-pole screw terminal | Cixi Kefa Elec | KF350-3.5-2P | Plugin,P=3.5mm | [C474892](https://jlcpcb.com/partdetail/C474892) | [PDF](https://www.lcsc.com/datasheet/lcsc_datasheet_2303171000_Cixi-Kefa-Elec-KF350-3-5-2P_C474892.pdf) | Extended, manualWeld | 6873 | 2026-09-28 |
| J5 | 1 | 3.5 mm pitch 2-pole screw terminal | Cixi Kefa Elec | KF350-3.5-2P | Plugin,P=3.5mm | [C474892](https://jlcpcb.com/partdetail/C474892) | [PDF](https://www.lcsc.com/datasheet/lcsc_datasheet_2303171000_Cixi-Kefa-Elec-KF350-3-5-2P_C474892.pdf) | Extended, manualWeld | 6873 | 2026-09-28 |
| J6 | 1 | 3.5 mm pitch 2-pole screw terminal | Cixi Kefa Elec | KF350-3.5-2P | Plugin,P=3.5mm | [C474892](https://jlcpcb.com/partdetail/C474892) | [PDF](https://www.lcsc.com/datasheet/lcsc_datasheet_2303171000_Cixi-Kefa-Elec-KF350-3-5-2P_C474892.pdf) | Extended, manualWeld | 6873 | 2026-09-28 |
| R1 | 1 | 5.1k: USB-C CC1 sink termination | UNI-ROYAL(Uniroyal Elec) | 0603WAF5101T5E | 0603 | [C23186](https://jlcpcb.com/partdetail/C23186) | [PDF](https://www.lcsc.com/datasheet/lcsc_datasheet_2206010116_UNI-ROYAL-Uniroyal-Elec-0603WAF5101T5E_C23186.pdf) | Basic, smtWeld | 24874911 | 2026-09-28 |
| R2 | 1 | 5.1k: USB-C CC2 sink termination | UNI-ROYAL(Uniroyal Elec) | 0603WAF5101T5E | 0603 | [C23186](https://jlcpcb.com/partdetail/C23186) | [PDF](https://www.lcsc.com/datasheet/lcsc_datasheet_2206010116_UNI-ROYAL-Uniroyal-Elec-0603WAF5101T5E_C23186.pdf) | Basic, smtWeld | 24874911 | 2026-09-28 |
| R3 | 1 | 27: USB D+ series termination | UNI-ROYAL(Uniroyal Elec) | 0603WAF270JT5E | 0603 | [C25190](https://jlcpcb.com/partdetail/C25190) | [PDF](https://www.lcsc.com/datasheet/lcsc_datasheet_2205311845_UNI-ROYAL-Uniroyal-Elec-0603WAF270JT5E_C25190.pdf) | Extended, smtWeld | 63296 | 2026-09-28 |
| R4 | 1 | 27: USB D- series termination | UNI-ROYAL(Uniroyal Elec) | 0603WAF270JT5E | 0603 | [C25190](https://jlcpcb.com/partdetail/C25190) | [PDF](https://www.lcsc.com/datasheet/lcsc_datasheet_2205311845_UNI-ROYAL-Uniroyal-Elec-0603WAF270JT5E_C25190.pdf) | Extended, smtWeld | 63296 | 2026-09-28 |
| R5 | 1 | 10k: Flash CS startup pullup | UNI-ROYAL(Uniroyal Elec) | 0603WAF1002T5E | 0603 | [C25804](https://jlcpcb.com/partdetail/C25804) | [PDF](https://www.lcsc.com/datasheet/lcsc_datasheet_2206010045_UNI-ROYAL-Uniroyal-Elec-0603WAF1002T5E_C25804.pdf) | Basic, smtWeld | 15191596 | 2026-09-28 |
| R6 | 1 | 1k: BOOTSEL current limitation | UNI-ROYAL(Uniroyal Elec) | 0603WAF1001T5E | 0603 | [C21190](https://jlcpcb.com/partdetail/C21190) | [PDF](https://www.lcsc.com/datasheet/lcsc_datasheet_2206010130_UNI-ROYAL-Uniroyal-Elec-0603WAF1001T5E_C21190.pdf) | Basic, smtWeld | 18075684 | 2026-09-28 |
| R7 | 1 | 1k: Crystal drive damping | UNI-ROYAL(Uniroyal Elec) | 0603WAF1001T5E | 0603 | [C21190](https://jlcpcb.com/partdetail/C21190) | [PDF](https://www.lcsc.com/datasheet/lcsc_datasheet_2206010130_UNI-ROYAL-Uniroyal-Elec-0603WAF1001T5E_C21190.pdf) | Basic, smtWeld | 18075684 | 2026-09-28 |
| R8 | 1 | 1k: Supervisor output isolation for RESET button | UNI-ROYAL(Uniroyal Elec) | 0603WAF1001T5E | 0603 | [C21190](https://jlcpcb.com/partdetail/C21190) | [PDF](https://www.lcsc.com/datasheet/lcsc_datasheet_2206010130_UNI-ROYAL-Uniroyal-Elec-0603WAF1001T5E_C21190.pdf) | Basic, smtWeld | 18075684 | 2026-09-28 |
| R9 | 1 | 10k: Power LED current limitation | UNI-ROYAL(Uniroyal Elec) | 0603WAF1002T5E | 0603 | [C25804](https://jlcpcb.com/partdetail/C25804) | [PDF](https://www.lcsc.com/datasheet/lcsc_datasheet_2206010045_UNI-ROYAL-Uniroyal-Elec-0603WAF1002T5E_C25804.pdf) | Basic, smtWeld | 15191596 | 2026-09-28 |
| R10 | 1 | 1k: Status LED current limitation | UNI-ROYAL(Uniroyal Elec) | 0603WAF1001T5E | 0603 | [C21190](https://jlcpcb.com/partdetail/C21190) | [PDF](https://www.lcsc.com/datasheet/lcsc_datasheet_2206010130_UNI-ROYAL-Uniroyal-Elec-0603WAF1001T5E_C21190.pdf) | Basic, smtWeld | 18075684 | 2026-09-28 |
| R11 | 1 | 100: STEP MOSFET gate series | UNI-ROYAL(Uniroyal Elec) | 0603WAF1000T5E | 0603 | [C22775](https://jlcpcb.com/partdetail/C22775) | [PDF](https://www.lcsc.com/datasheet/lcsc_datasheet_2411221126_UNI-ROYAL-Uniroyal-Elec-0603WAF1000T5E_C22775.pdf) | Basic, smtWeld | 10468872 | 2026-09-28 |
| R12 | 1 | 10k: STEP default off | UNI-ROYAL(Uniroyal Elec) | 0603WAF1002T5E | 0603 | [C25804](https://jlcpcb.com/partdetail/C25804) | [PDF](https://www.lcsc.com/datasheet/lcsc_datasheet_2206010045_UNI-ROYAL-Uniroyal-Elec-0603WAF1002T5E_C25804.pdf) | Basic, smtWeld | 15191596 | 2026-09-28 |
| R13 | 1 | 100: Arm MOSFET gate series | UNI-ROYAL(Uniroyal Elec) | 0603WAF1000T5E | 0603 | [C22775](https://jlcpcb.com/partdetail/C22775) | [PDF](https://www.lcsc.com/datasheet/lcsc_datasheet_2411221126_UNI-ROYAL-Uniroyal-Elec-0603WAF1000T5E_C22775.pdf) | Basic, smtWeld | 10468872 | 2026-09-28 |
| R14 | 1 | 10k: Arm default off | UNI-ROYAL(Uniroyal Elec) | 0603WAF1002T5E | 0603 | [C25804](https://jlcpcb.com/partdetail/C25804) | [PDF](https://www.lcsc.com/datasheet/lcsc_datasheet_2206010045_UNI-ROYAL-Uniroyal-Elec-0603WAF1002T5E_C25804.pdf) | Basic, smtWeld | 15191596 | 2026-09-28 |
| R15 | 1 | 100: DIR MOSFET gate series | UNI-ROYAL(Uniroyal Elec) | 0603WAF1000T5E | 0603 | [C22775](https://jlcpcb.com/partdetail/C22775) | [PDF](https://www.lcsc.com/datasheet/lcsc_datasheet_2411221126_UNI-ROYAL-Uniroyal-Elec-0603WAF1000T5E_C22775.pdf) | Basic, smtWeld | 10468872 | 2026-09-28 |
| R16 | 1 | 10k: DIR default off | UNI-ROYAL(Uniroyal Elec) | 0603WAF1002T5E | 0603 | [C25804](https://jlcpcb.com/partdetail/C25804) | [PDF](https://www.lcsc.com/datasheet/lcsc_datasheet_2206010045_UNI-ROYAL-Uniroyal-Elec-0603WAF1002T5E_C25804.pdf) | Basic, smtWeld | 15191596 | 2026-09-28 |
| R17 | 1 | 100k: Driver default disabled while powered | UNI-ROYAL(Uniroyal Elec) | 0603WAF1003T5E | 0603 | [C25803](https://jlcpcb.com/partdetail/C25803) | [PDF](https://www.lcsc.com/datasheet/lcsc_datasheet_2206010045_UNI-ROYAL-Uniroyal-Elec-0603WAF1003T5E_C25803.pdf) | Basic, smtWeld | 20868686 | 2026-09-28 |
| R18 | 1 | 100: Enable inverter gate series | UNI-ROYAL(Uniroyal Elec) | 0603WAF1000T5E | 0603 | [C22775](https://jlcpcb.com/partdetail/C22775) | [PDF](https://www.lcsc.com/datasheet/lcsc_datasheet_2411221126_UNI-ROYAL-Uniroyal-Elec-0603WAF1000T5E_C22775.pdf) | Basic, smtWeld | 10468872 | 2026-09-28 |
| R19 | 1 | 100k: Enable command default off | UNI-ROYAL(Uniroyal Elec) | 0603WAF1003T5E | 0603 | [C25803](https://jlcpcb.com/partdetail/C25803) | [PDF](https://www.lcsc.com/datasheet/lcsc_datasheet_2206010045_UNI-ROYAL-Uniroyal-Elec-0603WAF1003T5E_C25803.pdf) | Basic, smtWeld | 20868686 | 2026-09-28 |
| R20 | 1 | 1k: Minimum limit input series protection | UNI-ROYAL(Uniroyal Elec) | 0603WAF1001T5E | 0603 | [C21190](https://jlcpcb.com/partdetail/C21190) | [PDF](https://www.lcsc.com/datasheet/lcsc_datasheet_2206010130_UNI-ROYAL-Uniroyal-Elec-0603WAF1001T5E_C21190.pdf) | Basic, smtWeld | 18075684 | 2026-09-28 |
| R21 | 1 | 10k: Minimum limit open-wire detection | UNI-ROYAL(Uniroyal Elec) | 0603WAF1002T5E | 0603 | [C25804](https://jlcpcb.com/partdetail/C25804) | [PDF](https://www.lcsc.com/datasheet/lcsc_datasheet_2206010045_UNI-ROYAL-Uniroyal-Elec-0603WAF1002T5E_C25804.pdf) | Basic, smtWeld | 15191596 | 2026-09-28 |
| R22 | 1 | 1k: Maximum limit input series protection | UNI-ROYAL(Uniroyal Elec) | 0603WAF1001T5E | 0603 | [C21190](https://jlcpcb.com/partdetail/C21190) | [PDF](https://www.lcsc.com/datasheet/lcsc_datasheet_2206010130_UNI-ROYAL-Uniroyal-Elec-0603WAF1001T5E_C21190.pdf) | Basic, smtWeld | 18075684 | 2026-09-28 |
| R23 | 1 | 10k: Maximum limit open-wire detection | UNI-ROYAL(Uniroyal Elec) | 0603WAF1002T5E | 0603 | [C25804](https://jlcpcb.com/partdetail/C25804) | [PDF](https://www.lcsc.com/datasheet/lcsc_datasheet_2206010045_UNI-ROYAL-Uniroyal-Elec-0603WAF1002T5E_C25804.pdf) | Basic, smtWeld | 15191596 | 2026-09-28 |
| R24 | 1 | 100k: 5V measurement upper divider | UNI-ROYAL(Uniroyal Elec) | 0603WAF1003T5E | 0603 | [C25803](https://jlcpcb.com/partdetail/C25803) | [PDF](https://www.lcsc.com/datasheet/lcsc_datasheet_2206010045_UNI-ROYAL-Uniroyal-Elec-0603WAF1003T5E_C25803.pdf) | Basic, smtWeld | 20868686 | 2026-09-28 |
| R25 | 1 | 100k: 5V measurement lower divider | UNI-ROYAL(Uniroyal Elec) | 0603WAF1003T5E | 0603 | [C25803](https://jlcpcb.com/partdetail/C25803) | [PDF](https://www.lcsc.com/datasheet/lcsc_datasheet_2206010045_UNI-ROYAL-Uniroyal-Elec-0603WAF1003T5E_C25803.pdf) | Basic, smtWeld | 20868686 | 2026-09-28 |
| C1 | 1 | 1uF: USB input bypass | Samsung Electro-Mechanics | CL05A105KA5NQNC | 0402 | [C52923](https://jlcpcb.com/partdetail/C52923) | [PDF](https://www.lcsc.com/datasheet/lcsc_datasheet_2304140030_Samsung-Electro-Mechanics-CL05A105KA5NQNC_C52923.pdf) | Basic, smtWeld | 4535520 | 2026-09-28 |
| C2 | 1 | 1uF: LDO input stability | Samsung Electro-Mechanics | CL05A105KA5NQNC | 0402 | [C52923](https://jlcpcb.com/partdetail/C52923) | [PDF](https://www.lcsc.com/datasheet/lcsc_datasheet_2304140030_Samsung-Electro-Mechanics-CL05A105KA5NQNC_C52923.pdf) | Basic, smtWeld | 4535520 | 2026-09-28 |
| C3 | 1 | 2.2uF: LDO output stability | Samsung Electro-Mechanics | CL21B225KAFNNNE | 0805 | [C19110](https://jlcpcb.com/partdetail/C19110) | [PDF](https://www.lcsc.com/datasheet/lcsc_datasheet_2304140030_Samsung-Electro-Mechanics-CL21B225KAFNNNE_C19110.pdf) | Extended, smtWeld | 72521 | 2026-09-28 |
| C4 | 1 | 1uF: RP2040 VREG_IN stability | Samsung Electro-Mechanics | CL05A105KA5NQNC | 0402 | [C52923](https://jlcpcb.com/partdetail/C52923) | [PDF](https://www.lcsc.com/datasheet/lcsc_datasheet_2304140030_Samsung-Electro-Mechanics-CL05A105KA5NQNC_C52923.pdf) | Basic, smtWeld | 4535520 | 2026-09-28 |
| C5 | 1 | 1uF: RP2040 VREG_OUT stability | Samsung Electro-Mechanics | CL05A105KA5NQNC | 0402 | [C52923](https://jlcpcb.com/partdetail/C52923) | [PDF](https://www.lcsc.com/datasheet/lcsc_datasheet_2304140030_Samsung-Electro-Mechanics-CL05A105KA5NQNC_C52923.pdf) | Basic, smtWeld | 4535520 | 2026-09-28 |
| C6 | 1 | 100nF: U1 IOVDD pin1 bypass | Samsung Electro-Mechanics | CL05B104KO5NNNC | 0402 | [C1525](https://jlcpcb.com/partdetail/C1525) | [PDF](https://www.lcsc.com/datasheet/lcsc_datasheet_2304140030_Samsung-Electro-Mechanics-CL05B104KO5NNNC_C1525.pdf) | Basic, smtWeld | 17973853 | 2026-09-28 |
| C7 | 1 | 100nF: U1 IOVDD pin10 bypass | Samsung Electro-Mechanics | CL05B104KO5NNNC | 0402 | [C1525](https://jlcpcb.com/partdetail/C1525) | [PDF](https://www.lcsc.com/datasheet/lcsc_datasheet_2304140030_Samsung-Electro-Mechanics-CL05B104KO5NNNC_C1525.pdf) | Basic, smtWeld | 17973853 | 2026-09-28 |
| C8 | 1 | 100nF: U1 IOVDD pin22 bypass | Samsung Electro-Mechanics | CL05B104KO5NNNC | 0402 | [C1525](https://jlcpcb.com/partdetail/C1525) | [PDF](https://www.lcsc.com/datasheet/lcsc_datasheet_2304140030_Samsung-Electro-Mechanics-CL05B104KO5NNNC_C1525.pdf) | Basic, smtWeld | 17973853 | 2026-09-28 |
| C9 | 1 | 100nF: U1 DVDD pin23 bypass | Samsung Electro-Mechanics | CL05B104KO5NNNC | 0402 | [C1525](https://jlcpcb.com/partdetail/C1525) | [PDF](https://www.lcsc.com/datasheet/lcsc_datasheet_2304140030_Samsung-Electro-Mechanics-CL05B104KO5NNNC_C1525.pdf) | Basic, smtWeld | 17973853 | 2026-09-28 |
| C10 | 1 | 100nF: U1 IOVDD pin33 bypass | Samsung Electro-Mechanics | CL05B104KO5NNNC | 0402 | [C1525](https://jlcpcb.com/partdetail/C1525) | [PDF](https://www.lcsc.com/datasheet/lcsc_datasheet_2304140030_Samsung-Electro-Mechanics-CL05B104KO5NNNC_C1525.pdf) | Basic, smtWeld | 17973853 | 2026-09-28 |
| C11 | 1 | 100nF: U1 IOVDD pin42 and ADC bypass | Samsung Electro-Mechanics | CL05B104KO5NNNC | 0402 | [C1525](https://jlcpcb.com/partdetail/C1525) | [PDF](https://www.lcsc.com/datasheet/lcsc_datasheet_2304140030_Samsung-Electro-Mechanics-CL05B104KO5NNNC_C1525.pdf) | Basic, smtWeld | 17973853 | 2026-09-28 |
| C12 | 1 | 100nF: U1 USB_VDD and IOVDD49 bypass | Samsung Electro-Mechanics | CL05B104KO5NNNC | 0402 | [C1525](https://jlcpcb.com/partdetail/C1525) | [PDF](https://www.lcsc.com/datasheet/lcsc_datasheet_2304140030_Samsung-Electro-Mechanics-CL05B104KO5NNNC_C1525.pdf) | Basic, smtWeld | 17973853 | 2026-09-28 |
| C13 | 1 | 100nF: U1 DVDD pin50 bypass | Samsung Electro-Mechanics | CL05B104KO5NNNC | 0402 | [C1525](https://jlcpcb.com/partdetail/C1525) | [PDF](https://www.lcsc.com/datasheet/lcsc_datasheet_2304140030_Samsung-Electro-Mechanics-CL05B104KO5NNNC_C1525.pdf) | Basic, smtWeld | 17973853 | 2026-09-28 |
| C14 | 1 | 100nF: Flash bypass | Samsung Electro-Mechanics | CL05B104KO5NNNC | 0402 | [C1525](https://jlcpcb.com/partdetail/C1525) | [PDF](https://www.lcsc.com/datasheet/lcsc_datasheet_2304140030_Samsung-Electro-Mechanics-CL05B104KO5NNNC_C1525.pdf) | Basic, smtWeld | 17973853 | 2026-09-28 |
| C15 | 1 | 15pF: Crystal 10pF load network | FH (Guangdong Fenghua Advanced Tech) | 0402CG150J500NT | 0402 | [C1548](https://jlcpcb.com/partdetail/C1548) | [PDF](https://www.lcsc.com/datasheet/lcsc_datasheet_2304140030_FH--Guangdong-Fenghua-Advanced-Tech-0402CG150J500NT_C1548.pdf) | Basic, smtWeld | 1332539 | 2026-09-28 |
| C16 | 1 | 15pF: Crystal 10pF load network | FH (Guangdong Fenghua Advanced Tech) | 0402CG150J500NT | 0402 | [C1548](https://jlcpcb.com/partdetail/C1548) | [PDF](https://www.lcsc.com/datasheet/lcsc_datasheet_2304140030_FH--Guangdong-Fenghua-Advanced-Tech-0402CG150J500NT_C1548.pdf) | Basic, smtWeld | 1332539 | 2026-09-28 |
| C17 | 1 | 100nF: Minimum limit RC filter | YAGEO | CC0603KRX7R9BB104 | 0603 | [C14663](https://jlcpcb.com/partdetail/C14663) | [PDF](https://www.lcsc.com/datasheet/lcsc_datasheet_2211101700_YAGEO-CC0603KRX7R9BB104_C14663.pdf) | Basic, smtWeld | 45050464 | 2026-09-28 |
| C18 | 1 | 100nF: Maximum limit RC filter | YAGEO | CC0603KRX7R9BB104 | 0603 | [C14663](https://jlcpcb.com/partdetail/C14663) | [PDF](https://www.lcsc.com/datasheet/lcsc_datasheet_2211101700_YAGEO-CC0603KRX7R9BB104_C14663.pdf) | Basic, smtWeld | 45050464 | 2026-09-28 |
| C19 | 1 | 100nF: Supply ADC filtering | YAGEO | CC0603KRX7R9BB104 | 0603 | [C14663](https://jlcpcb.com/partdetail/C14663) | [PDF](https://www.lcsc.com/datasheet/lcsc_datasheet_2211101700_YAGEO-CC0603KRX7R9BB104_C14663.pdf) | Basic, smtWeld | 45050464 | 2026-09-28 |
| R26 | 1 | 75k: Driver feedback upper series resistor | YAGEO | RT0603BRD0775KL | 0603 | [C723587](https://jlcpcb.com/partdetail/C723587) | [PDF](https://wmsc.lcsc.com/wmsc/upload/file/pdf/v2/lcsc/2008171334_YAGEO-RT0603BRD0775KL_C723587.pdf) | Extended, smtWeld | 156921 | 2026-09-28 |
| R27 | 1 | 10k: Driver feedback upper series resistor | YAGEO | RT0603BRD0710KL | 0603 | [C95204](https://jlcpcb.com/partdetail/C95204) | [PDF](https://wmsc.lcsc.com/wmsc/upload/file/pdf/v2/lcsc/1811082117_YAGEO-RT0603BRD0710KL_C95204.pdf) | Extended, smtWeld | 1162560 | 2026-09-28 |
| R28 | 1 | 10k: Driver feedback lower resistor: 4.75 V nominal | YAGEO | RT0603BRD0710KL | 0603 | [C95204](https://jlcpcb.com/partdetail/C95204) | [PDF](https://wmsc.lcsc.com/wmsc/upload/file/pdf/v2/lcsc/1811082117_YAGEO-RT0603BRD0710KL_C95204.pdf) | Extended, smtWeld | 1162560 | 2026-09-28 |
| R29 | 1 | 100k: Driver load switch defaults off | UNI-ROYAL(Uniroyal Elec) | 0603WAF1003T5E | 0603 | [C25803](https://jlcpcb.com/partdetail/C25803) | [PDF](https://www.lcsc.com/datasheet/lcsc_datasheet_2206010045_UNI-ROYAL-Uniroyal-Elec-0603WAF1003T5E_C25803.pdf) | Basic, smtWeld | 20868686 | 2026-09-28 |
| R30 | 1 | 100k: Driver regulator defaults off | UNI-ROYAL(Uniroyal Elec) | 0603WAF1003T5E | 0603 | [C25803](https://jlcpcb.com/partdetail/C25803) | [PDF](https://www.lcsc.com/datasheet/lcsc_datasheet_2206010045_UNI-ROYAL-Uniroyal-Elec-0603WAF1003T5E_C25803.pdf) | Basic, smtWeld | 20868686 | 2026-09-28 |
| R31 | 1 | 10k: Discharge driver rail after shutdown | UNI-ROYAL(Uniroyal Elec) | 0603WAF1002T5E | 0603 | [C25804](https://jlcpcb.com/partdetail/C25804) | [PDF](https://www.lcsc.com/datasheet/lcsc_datasheet_2206010045_UNI-ROYAL-Uniroyal-Elec-0603WAF1002T5E_C25804.pdf) | Basic, smtWeld | 15191596 | 2026-09-28 |
| R32 | 1 | 100k: Driver branch current limit (100k, 1%) | UNI-ROYAL(Uniroyal Elec) | 0603WAF1003T5E | 0603 | [C25803](https://jlcpcb.com/partdetail/C25803) | [PDF](https://www.lcsc.com/datasheet/lcsc_datasheet_2206010045_UNI-ROYAL-Uniroyal-Elec-0603WAF1003T5E_C25803.pdf) | Basic, smtWeld | 20868686 | 2026-09-28 |
| R33 | 1 | 10k: Open-drain current-limit fault pull-up | UNI-ROYAL(Uniroyal Elec) | 0603WAF1002T5E | 0603 | [C25804](https://jlcpcb.com/partdetail/C25804) | [PDF](https://www.lcsc.com/datasheet/lcsc_datasheet_2206010045_UNI-ROYAL-Uniroyal-Elec-0603WAF1002T5E_C25804.pdf) | Basic, smtWeld | 15191596 | 2026-09-28 |
| C21 | 1 | 22uF: Buck-boost input reservoir | Samsung Electro-Mechanics | CL21A226MAQNNNE | 0805 | [C45783](https://jlcpcb.com/partdetail/C45783) | [PDF](https://www.lcsc.com/datasheet/lcsc_datasheet_2304140030_Samsung-Electro-Mechanics-CL21A226MAQNNNE_C45783.pdf) | Basic, smtWeld | 3469394 | 2026-09-28 |
| C22 | 1 | 22uF: Buck-boost output reservoir | Samsung Electro-Mechanics | CL21A226MAQNNNE | 0805 | [C45783](https://jlcpcb.com/partdetail/C45783) | [PDF](https://www.lcsc.com/datasheet/lcsc_datasheet_2304140030_Samsung-Electro-Mechanics-CL21A226MAQNNNE_C45783.pdf) | Basic, smtWeld | 3469394 | 2026-09-28 |
| C23 | 1 | 22uF: Buck-boost output reservoir | Samsung Electro-Mechanics | CL21A226MAQNNNE | 0805 | [C45783](https://jlcpcb.com/partdetail/C45783) | [PDF](https://www.lcsc.com/datasheet/lcsc_datasheet_2304140030_Samsung-Electro-Mechanics-CL21A226MAQNNNE_C45783.pdf) | Basic, smtWeld | 3469394 | 2026-09-28 |
| C24 | 1 | 100nF: Buck-boost analog bypass | Samsung Electro-Mechanics | CL05B104KO5NNNC | 0402 | [C1525](https://jlcpcb.com/partdetail/C1525) | [PDF](https://www.lcsc.com/datasheet/lcsc_datasheet_2304140030_Samsung-Electro-Mechanics-CL05B104KO5NNNC_C1525.pdf) | Basic, smtWeld | 17973853 | 2026-09-28 |
| C25 | 1 | 100nF: Supervisor supply bypass | Samsung Electro-Mechanics | CL05B104KO5NNNC | 0402 | [C1525](https://jlcpcb.com/partdetail/C1525) | [PDF](https://www.lcsc.com/datasheet/lcsc_datasheet_2304140030_Samsung-Electro-Mechanics-CL05B104KO5NNNC_C1525.pdf) | Basic, smtWeld | 17973853 | 2026-09-28 |
| C26 | 1 | 1uF: Load switch input bypass | Samsung Electro-Mechanics | CL05A105KA5NQNC | 0402 | [C52923](https://jlcpcb.com/partdetail/C52923) | [PDF](https://www.lcsc.com/datasheet/lcsc_datasheet_2304140030_Samsung-Electro-Mechanics-CL05A105KA5NQNC_C52923.pdf) | Basic, smtWeld | 4535520 | 2026-09-28 |

Four 3.2 mm NPTH holes and eleven bare copper test pads are PCB features, not purchased parts. M3 fasteners/standoffs are not supplied; select hardware within the 8 mm diameter clearance envelope after enclosure design. Motor, driver, USB cable and limit switches are external equipment.

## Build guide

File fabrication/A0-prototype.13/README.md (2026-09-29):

# A0 / 0.1.0-prototype.13 manufacturing review package

**Untested prototype. Design checks pass; manufacturer/assembler acceptance is pending. Not yet approved to order.**

Board: **RP2040 USB-C Single-Axis Stepper Motion Controller for External DM542T Drivers with STEP/DIR/ENABLE Outputs and Dual Limit-Switch Inputs**.

The native `gerbers.zip` and unchanged `exported/` files come from one validated
routed Circuit JSON. The generator is source-built with the explicit fixes and
provenance in `../../tooling/`. No copper, generated JSON, or Gerber was patched.
Copper, holes, vias, and component positions remain identical to prototype.12.

Upload `gerbers.zip`, `assembly-bom.csv`, and `exported/pick_and_place.csv` for
review. The complete authored BOM has accurate package descriptions and exact
LCSC codes; the native BOM inside the ZIP retains sparse importer descriptions.
The placement file contains 85 fitted designators, all on top, matching the BOM.
Coordinates are millimetres from the board centre, X right and Y up. Rotations
use the native JLCPCB exporter convention. See `assembly.svg` and F_Fab for part
references, pin-one marks, component outlines, and assembly orientation.

## Fabrication specification

- 90 × 60 × 1.0 mm FR-4; two copper layers; nominal 1 oz outer copper.
- Green solder mask, white top legend; ENIG finish for the fine-pitch MCU.
- Outline: X ±45 mm, Y ±30 mm. Routed edges; no V-cuts or castellations.
- Four finished Ø3.2 mm NPTH mounting holes at (±40, ±25) mm. Additional USB
  locating holes are in the NPTH file. Preserve plated USB slots (Excellon G85),
  Ø1.0 mm terminal holes, and Ø0.3 mm vias in the plated drill file.
- Copper-edge clearance ≥0.5 mm; copper is ≥4.01059 mm from mounting centres.
- Preserve the supplied mask apertures. Vias are tented; exposed test pads remain
  accessible. J2–J6 require through-hole soldering after reflow, not pin-in-paste.
- The assembler must design any necessary handling rails/tooling/fiducials on
  the production panel, retaining the finished 90 × 60 mm outline and connectors.

## Completed review and pending acceptance

There is no stencil paste on any of the eleven bare test pads or ten terminal
pad positions. The explicit terminal paste-control regression passes. Source
and Gerber text now include both requested bullet separators. Printed text is
≥1.016 mm high; all printed strokes are ≥0.15 mm. The actual-Gerber legend audit
checks exposed-pad clearance, outline margin, and text-to-text spacing.
Detailed small component references/outline artwork are retained on F_Fab;
the fabricated legend carries readable controls, indicators, test signals,
connector polarity, board identity, and REV A0.

Pending manufacturer review: confirm the 1.0 mm stackup and ENIG option; verify
USB slots/terminal hole fit; match every library part and its zero orientation
against the pad positions and pin-one/polarity marks; approve top stencil
thickness/apertures, including RP2040 and TPS63030 exposed pads and USB anchors;
confirm through-hole terminal assembly and production-panel handling. Default
SMT paste reduction remains the generator's 70% linear size. It requires stencil
engineering approval and is not asserted to be an optimized production stencil.

No manufacturer acceptance, purchase, assembled board, or physical test is
claimed. The stage-6 status remains pending until actual feedback is reviewed.

## Reproduce

Use the locked dependencies and ordinary `tsci build` / `tsci export ... --format
gerbers` commands from the board directory. Run `bun run test:fabrication`,
`firmware/.venv/bin/python scripts/check-silkscreen.py`, and the electrical tests.
`bun scripts/render-gerbers.cjs` renders the actual Gerbers; the preview script
renders the board without overlaying the separate assembly-note layer.

Manufacturer limits checked 2026-09-29:
[PCB capabilities](https://jlcpcb.com/capabilities/pcb-capabilities),
[BOM format](https://jlcpcb.com/help/article/bill-of-materials-for-pcb-assembly).

Prototype.13 adds schematic review notes and explicit USB plug-entry metadata. Physical copper, holes, paste, mask and legend geometry remain unchanged from prototype.12.

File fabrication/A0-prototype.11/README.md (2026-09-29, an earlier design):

# A0 / 0.1.0-prototype.11 manufacturing review package

**Untested prototype — NOT APPROVED TO ORDER OR CUT A STENCIL.**

The native `gerbers.zip` and its unchanged `exported/` contents were generated from the routed circuit identified in `manifest.json`. Copper, connectivity and dimensional checks pass. The package contains top/bottom copper, mask, paste and silk, the outline, plated/NPTH drills, the native BOM and a JLCPCB placement file. `assembly-bom.csv` is the complete authored sourcing BOM; the native BOM has matching codes but less descriptive fields.

Target construction: 90 × 60 × 1.0 mm FR-4, two copper layers, nominal 1 oz outer copper, top component assembly. All 85 fitted designators match the placement file. Placement coordinates are millimetres relative to board centre, positive X right and positive Y up; rotations are the native JLCPCB export convention. The assembler must verify component library zero orientations, polarity and connector orientation before acceptance. No assembler review has occurred.

The outline spans X ±45 mm and Y ±30 mm. Four 3.2 mm finished mounting holes are NPTH at (±40, ±25) mm. The NPTH file also contains the USB locating holes. The plated drill file contains the USB shell slots, 1.0 mm terminal holes and 0.3 mm vias. Slots use Excellon G85 commands. Copper stays at least 0.5 mm from the board edge and 4.01059 mm from mounting centres.

## Blocking stencil issue

The installed `@tscircuit/core` 0.0.1971 unconditionally generates top and bottom solder-paste circles for circular plated holes. Its public `CirclePlatedHoleProps` has no independent paste control. The ten J2–J6 terminal positions therefore have twenty unwanted paste openings, across both stencil layers. These terminals are not intended for pin-in-paste assembly. `bun run test:fabrication` intentionally fails and records this defect in `review.json`.

Paste on all eleven bare test pads has been removed through supported source properties, without changing their copper or exposed solder-mask openings. The through-hole issue requires a proper core/API fix followed by regeneration, not editing exported Gerbers or suppressing the check. The exported font also omits the two bullet glyphs in the requested subtitle; the source text is exact, but this needs an export/font fix before final silkscreen approval. Stencil aperture/reduction approval for the exposed pads and fine-pitch ICs is also pending assembler feedback.

No order has been placed. No physical board, assembly, programming, USB, loaded output or motor test has been performed.

## Reproduce

From the board directory, build the current source, then use the installed CLI's supported `export ... --format gerbers` option with `dist/index/circuit.json` and an absolute output path. Run `python3 scripts/check-fabrication.py` after extracting the native archive. `bun scripts/render-gerbers.cjs` renders the actual exported layers with the pinned gerber-to-svg 4.2.8 dependency. Full gate results are in the board's VALIDATION.md.

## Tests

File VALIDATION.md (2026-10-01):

# Validation record — revision A0

Product: **RP2040 USB-C Single-Axis Stepper Motion Controller for External DM542T Drivers with STEP/DIR/ENABLE Outputs and Dual Limit-Switch Inputs**

Reviewed 2026-10-01 local time. **Untested prototype. Current prototype.19 has 84 native errors, 29 native shorts findings and three independently shorted net groups. Not fabrication ready.** GitHub and tscircuit source publication is user-authorized. This board now has its own Git repository. Earlier source/dependency manifests identify pre-Git states; they do not constitute recoverable complete source snapshots. A0-draft-2 manifests are historical; the power circuit and firmware have changed since then.

## Stage status

| Stage | Status | Evidence / remaining work |
|---|---|---|
| 1. Confirm requirements | in progress | Historical A0: four-layer 90×60×1 mm candidate. New combined-driver proposal: TMC2209, 15 V nominal PD and selected 17HS08-1004S motor; protection/stackup still require review. |
| 2. Review schematic and BOM | blocked | New JLCPCB-only requirement invalidates the earlier wrapper-based gate; C55266 imports as a switch and requires an upstream correction. Historical review: DESIGN-REVIEW.md; 85 exact sourced components; regulated driver voltage/current budgets, supervisor, USB sequencing/suspend and overload handling reviewed. Physical electrical limits remain unmeasured. |
| 3. Validate placement before routing | blocked | Dependent on renewed stage-2 import validation. Historical result: Candidate 19j: native unrouted build and invariants pass; zero placement DRC errors/warnings; PCB reviewed. All five required pre-routing checks exit 0. Eight native A4 sheets reviewed; two pin-padding suggestions accepted for readability. |
| 4. Route and validate copper | blocked | Prototype.19j: 84 native errors; 29 native shorts findings; three independently shorted net groups; three via-pair, 13 ordinary drill-to-pad and 29 reserved-plane violations. |
| 5. Automated and visual routed checks | blocked | Prototype.19j routing rejected. Four copper layers inspected; snapshot verification fails, no snapshot accepted. All eight A4 pages and 273 unchanged pin/net mappings verified. |
| 6. Approve prototype fabrication | blocked | No prototype.19 manufacturing export; dist is rejected diagnostic output only. Historical exports remain withdrawn from ordering. |
| 7. Test physical prototype | not started | No physical hardware. BRING-UP.md defines required measurements. |
| 8. Prepare store release | in progress | Exact name and revision in README, metadata and prototype source listing. GitHub/tscircuit projects created; source publication authorized. Sale-ready release remains incomplete. |

## Requirements and selected references

- USB-C nominal 5 V, full-speed USB data, one RP2040, one external STEPPERONLINE DM542T **V4.0**, manual rev 4.0 / October 2020, S2 at **5 V**. [Official manual](https://www.omc-stepperonline.com/download/DM542T_V4.0.pdf).
- Common-anode STEP/DIR/ENA, regulated 4.75 V nominal, 7–16 mA per active driver input, 4.5–5 V target at the driver. ≤1 Ω control-pair cable loop. No motor power, external injection or 24 V sensors. Indoor 0–50 °C intended range.
- 500 mA USB configuration request. Design budgets: 80 mA before configuration, about 160 mA running, about 386 mA including branch current limit; attachment capacitance 9.35 µF. Suspend must be ≤2.5 mA. These are allocations, not measurements; see evidence/power-budget.json and BRING-UP.md.
- Normally-closed dry-contact limits, reset/boot buttons, LEDs and 11 bare 1.4 mm test pads. Broken wires assert limits. Firmware cap 2000 steps/s, 10 µs high/low minimums, 2 ms direction guard, ≥200 ms enable lead, 1 s heartbeat timeout.
- User explicitly authorized a **new outline and mounting pattern**, replacing the original matching requirement: 90×60×1 mm FR-4, four-layer candidate, top assembly, four 3.2 mm finished NPTH holes at centered (±40,±25) mm, 80×50 mm spacing. Four native 4.03 mm-radius keepouts on all four layers reserve the 4 mm hardware clearance; 1 mm remains between each clearance circle and board edge. M3 hardware must fit this envelope. No specific enclosure fit claimed.
- JLCPCB target: 1 oz outer copper, signal width and copper spacing ≥0.15 mm, main power trunks 0.4/0.5 mm, vias ≥0.3 mm drill / 0.6 mm pad, via-hole separation ≥0.46 mm and other plated-drill separation ≥0.25 mm, copper-edge clearance ≥0.5 mm. [Manufacturer capabilities](https://jlcpcb.com/capabilities/pcb-capabilities). Fine-pitch escape necks and actual current capacity must be assessed from routed geometry. No controlled impedance claim; the exact four-layer dielectric stackup remains unconfirmed.

## Reproducibility

Bun 1.3.9; tscircuit 0.0.2646; CLI 0.1.2172; core 0.0.1971-a0.3; capacity-autorouter 0.0.919-a0.2; props 0.0.666-a0.1; alphabet 0.0.25-a0.1; TypeScript 5.9.3; Biome 2.5.14; @types/node 22.15.30; pinned bun.lock. Run commands only inside this board directory. Catalog electrical footprints are preserved; prototype.12 moves detailed reference artwork to the fabrication layer and adjusts pin-one legend positions/stroke widths. Locally authored symbol/footprint wrappers are explicit. Manufacturer PDFs remain local; official JLC assembly-stock snapshots are in references/catalog/. Datasheet URLs are in the BOM and design review. Individual catalog dates use UTC.

Firmware uses Pico SDK 2.2.0 (`a1438dff1d38bd9c65dbd693f0e5db4b9ae91779`), TinyUSB `86ad6e56c1700e85f1c5678607a762cfe3aa2f47`, CMake 3.31.6, Arm GNU 13.2.Rel1 / GCC 13.2.1. Exact archive hashes and subset-extraction record are in evidence/toolchain-install.json. Compiler binaries and SDK internals are unchanged; baseline and Cortex-M0+ runtime libraries are included. Firmware README records reconstruction/build/flash commands. ELF/BIN/HEX are software artifacts, not evidence of successful flashing.

Earlier disk exhaustion and a system compiler missing nosys.specs were resolved with task-local dependencies and the official Arm toolchain. Native `keepout` is the installed supported spelling. Manufacturing tolerances are direct board props, not a nested routingTolerances prop. Typechecking exposed and corrected the unsupported form before routing. No type escapes, ignored errors, DRC suppression or installed-artifact patches are used. Prototype.12 includes tested source-built generator forks, with official base commits, source patches, regression fixtures and hashed package archives in tooling/.

## Historical baseline commands and evidence

These are earlier baseline results, not acceptance of the current routed board. Current prototype.19 results and logs are recorded at the end of this file.

| Command | Result / evidence |
|---|---|
| `bun run format` / `bun run format:check` | Authored source formatting; evidence/a0-format.log / a0-format-check.log |
| `bun run typecheck` | evidence/a0-typecheck.log |
| `bun run bom` | 85 fitted electronic components, all exact codes and positive official assembly-eligible stock; evidence/a0-bom.log, bom.csv, BOM.md |
| `python3 scripts/power-budget.py` | Assertions pass; evidence/power-budget.log and .json |
| `bun run test:firmware` | Sanitized parser/motion tests pass; evidence/a0-motion-tests.log |
| `bun run test:power` | Sanitized sequencing, suspend/resume, undervoltage, wrap and overload-latch tests pass; evidence/a0-power-tests.log |
| `firmware/.venv/bin/cmake --build firmware/build-arm -j 4` | Cross-build passes with warnings as errors; evidence/a0-firmware-build.log |
| `bunx tsci check netlist index.circuit.tsx` | evidence/a0-netlist.log |
| `bunx tsci check pin_specification index.circuit.tsx` | evidence/a0-pin-specification.log |
| `bunx tsci check source index.circuit.tsx` | evidence/a0-source.log |
| `bunx tsci check schematic-placement index.circuit.tsx` | evidence/a0-schematic-placement.log |
| `bunx tsci check placement index.circuit.tsx` | evidence/a0-placement.log |
| `bunx tsci build index.circuit.tsx --pcb-png --pcb-svgs --schematic-svgs` | Unrouted gate evidence/a0-unrouted-build.log; later routed build must be recorded separately |
| `bun run test:board` | Generated connectivity/BOM and unrouted mechanical invariants; evidence/a0-board-tests.log |
| `bunx tsci check routing-difficulty index.circuit.tsx` | Congestion report: evidence/a0-routing-difficulty.log |
| `bunx tsci export index.circuit.tsx --format schematic-pdf --output dist/index/schematic.pdf` | evidence/a0-schematic-export.log, rendered review evidence/a0-schematic-review.png |
| `bunx tsci check shorts dist/index/circuit.json` | Current prototype.12 passes; earlier failures remain in the historical records below |
| `bunx tsci snapshot index.circuit.tsx` | Prototype.12 PCB change reviewed and accepted; PCB and schematic both match in CI mode |

## Review and warnings

Unrouted PCB reviewed for component/courtyard clearance, terminal wire entry, USB access, mounting envelopes and test-pad access. Top-bank terminals face upward, lower bank downward. The exact requested short title, subtitle and REV A0 are visible. Moving the USB connector inward by 0.5 mm corrects its shell-anchor copper-edge violation under the specified 0.5 mm rule. Its mouth remains accessible from the edge; reserve plug/enclosure access. Ordinary silkscreen/component cleanup and final mask/paste checks remain part of routed/fabrication review.

Schematic sheet enlarged to contain all sections. TPS2553 importer incorrectly uses a two-terminal switch; its local six-pin chip model now shows every function. Local wrappers restore missing reference text on custom symbols while preserving source imports. Numeric pin maps and exact BOM mappings are tested against emitted circuit JSON.

The 35 generic-model pin warnings concern imported connectors, FETs, fuse and crystal. They have no dedicated supply input in the IC sense; missing power/ground classifications and generic refdes conventions are accepted model limitations after manual pin review. No fictitious power pins were added to silence them. F1's horizontal power-path symbol has a cosmetic vertical-orientation recommendation; it remains electrically legible. Bare test pads have no component body; their copper/probe access is reviewed explicitly.

Terminal drawing KF350-3.50 Rev A / 2021-03-13 was inspected: 3.5 mm pitch, 0.8 mm leads, 1 mm recommended holes, 6.9 mm depth, 8.8 mm body height and 3.4 mm lead length. Allow 5 mm below the PCB and overhead screwdriver access. Standard PCBA/manual-weld eligibility and orientation must be confirmed during assembler review. No assembler feedback has been obtained.

## Physical and release limits

No prototype, scope captures, current/temperature measurements, motor tests or physical photos exist. Stage 7 remains pending regardless of software results. Loss of controller power or shutdown of VDRV releases ENA and can restore driver holding torque. This is not a safety-rated torque-off device. STORE-LISTING.md describes an incomplete prototype source release. The user authorized source publication on 2026-09-29; no fabrication order is authorized.

Stage-3 acceptance: all five required checks exited 0. Netlist/source report no errors; pin check has the 35 reviewed generic-model warnings. Final schematic-only flash relocation removed label collisions and did not change PCB placement/connectivity. Full rebuild and board invariant tests passed after that move. The reviewed PCB and schematic are preserved before routing.

## Routing investigation

The first native route generated 216 traces and 228 through vias, all 0.3/0.6 mm, with minimum wire width 0.15 mm. Its shorts check passed, but two RUN-net via pairs violated the 0.25 mm drill spacing. Independent geometry review additionally found two same-net drill holes intersecting U5 SMD pads. Neither result is accepted. Preserved candidate: evidence/routing-attempt-1/; logs a0-routed-build-1.log, a0-shorts-1.log and copper-measurements-1.json.

Explicit native local routes were added for the U5 ground pair, RUN escape and both converter-inductor connections. The second candidate introduced additional routing violations and shorts; it is preserved in evidence/routing-attempt-2/ and rejected. Native routing is being retried with additional phase clearance; board manufacturing checks remain unchanged.

The independent audit measured only 3.98074 mm copper distance from mounting centers because the circular pour exclusion uses straight polygon edges. Increasing the native keepout radius from 4.00 to 4.03 mm reserves the specified 4 mm hardware radius despite that approximation. Fresh placement check a0-placement-expanded-keepouts.log passes. This adds clearance; it does not relax a manufacturing rule.

Geometry audit: `firmware/.venv/bin/python scripts/measure-copper.py`, Shapely 2.1.2 / NumPy 2.5.3 (versions in evidence/geometry-tools-versions.txt). It checks all ordinary drills against SMD/test pads without excluding same-net pads, records trace/via dimensions and conservative copper edge/mounting distances. Native DRC/shorts remain mandatory. The empirical external-trace capacity estimate uses 30 µm copper and IPC-2221's coefficient 0.048; a 0.15 mm neck estimates 0.541 A at 10 °C rise, above the 0.386 A allocated input limit. This is a thermal design estimate, not a measurement; critical power paths and actual temperatures remain subject to review.

## Historical storage stop point (superseded by publication check below)

Disk exhaustion recurred at the four-layer preparation step. Copying the last candidate failed with ENOSPC; therefore **no four-layer modification or trial was completed**. A subsequent redundant two-layer build also failed while writing its results. The current source remains two-layer with native routing enabled, 4.03 mm keepouts and a bottom ground pour. Its latest complete electrical/placement checks remain relevant; routed acceptance is blocked.

The latest dist/index/circuit.json had extra trailing data after the failed write and was quarantined intact as evidence/enospc-corrupt-circuit.json.txt. It is not usable validation evidence. Previews in dist/index are rejected/stale and labeled in its README. Complete rejected candidates 1–3 and the accepted unrouted placement are preserved. Candidate 4 had 199 native errors before its later failed rewrite; its router input/output and log remain in dist/autorouter-debug-4/ and evidence/a0-routed-build-4.log. Candidate 4's attempted net selectors did not select the initial phase; the log shows only the implicit remaining phase ran. Those ineffective phase settings were removed, and experimental source files are preserved as text under evidence/ rather than treated as a successful repair.

Cleanup removed only this task's Python bytecode cache (19,480,508 bytes) and incomplete evidence copy. No unrelated files or source/dependency binaries were deleted. Disk free-space reporting fluctuated around 100–170 MB while actual writes failed. Several GB of stable free space are required before continuing.

Next: free storage; rebuild a complete current circuit; evaluate four layers with an internal ground plane under the brief's conditional two-layer preference; verify exact manufacturer's stackup if retained; revalidate affected placement/source and every copper layer. Resolve all native errors, shorts and independent drill/pad violations. Then run and visually review the required snapshot, generate/review manufacturing files and obtain assembler feedback. No snapshot or fabrication package is accepted. Physical stage 7 remains unperformed.

The tscircuit skill requires: “When the canonical approach is blocked, diagnose it. If it cannot be completed within scope, stop and report the blocker and the proper next action; never conceal it with a hack or fallback.” [Skill source](/Users/anassarkiz/.codex/skills/tscircuit/SKILL.md). Storage is the immediate execution blocker; failed copper checks independently prevent fabrication approval. No check was disabled or weakened.

Pre-publication source identity: evidence/source-manifest-A0-routing-blocked-5.json. Artifact inventory: evidence/artifact-manifest-A0-routing-blocked-5.json. These record the blocked state, including historical/rejected artifacts; they are not fabrication approval.

## Source publication check — 0.1.0-prototype.1

On 2026-09-29 the user required GitHub and tscircuit repositories and pushes for every version. Both public projects were created under AnasSarkiz. Storage recovered to approximately 26 GiB free. No electrical circuit or placement changes were made for publishing; prior schematic/BOM and unrouted placement reviews still apply. Package metadata, publication documentation and ignore rules changed. The exact tagged source is the first reproducible Git snapshot; older artifacts remain historical.

Fresh checks from this source:

- Formatting and TypeScript: passed (publish-format-check.log, publish-typecheck.log).
- Sanitized motion/parser and power-policy tests: passed (publish-motion-tests.log, publish-power-tests.log).
- Required pre-publish netlist and placement checks: passed with zero errors/warnings (publish-netlist.log, publish-placement.log).
- Native routed build with PCB PNG/SVG and schematic SVG: **failed**, exit 1, 199 emitted PCB errors (publish-build.log). Complete valid JSON is restored in dist/index and preserved under evidence/routing-prototype-1/. Errors include 50 trace, 9 pad/trace, 108 via/trace, 21 pad/pad, 1 via and 10 placement errors introduced by routed geometry.
- Native shorts check: **failed**, 26 reported raster/gerber findings; these are reported findings, not a claim of 26 unique electrical defects (publish-shorts.log).
- Routed board test: **failed** on the emitted errors (publish-board-tests.log).
- Independent copper audit: **failed**, 16 drill-to-pad violations; minimum trace width 0.15 mm; 212 vias with 0.3/0.6 mm drill/pad (publish-copper-measurements.log and copper-measurements-prototype-1.json).
- Current PCB overview inspected; dense MCU routing has visible overlaps. This rejected preview is not an accepted visual gate or physical photo. No snapshot accepted and no fabrication outputs approved.

The tscircuit CLI uploads sources and queues remote processing; successful upload is separate from a passing PCB build. The source package prominently discloses the failures. Local toolchains, private user brief, manufacturer PDF copies and corrupt output are excluded from both repositories. The tscircuit GitHub-app linkage request returned repository_not_accessible; direct authenticated CLI pushes to each service remain available. No permission bypass was used.

Next hardware work: resolve native routing/shorts and independent geometry failures, then complete routed visual/snapshot and fabrication gates. Current source is still two-layer; no four-layer trial has run. Source publication does not advance stages 4–7. See VERSIONING.md for the agreed push-every-version workflow.

Public export scope: the initial broad export was blocked by automatic approval review. The public snapshot contains authored board/firmware sources, component imports, the minimal supplier metadata used to reproduce the BOM, documentation, tests, and the concise public-validation.json record with artifact hashes. `.npmrc`, raw evidence/logs/generated renders, supplier reference downloads and private input remain local. Paths to those artifacts elsewhere in this document describe the local investigation archive, not files included in the public release. Historical whitespace warnings in generated evidence and the unchanged third-party license were reviewed; authored source whitespace checks pass.

## Placement iteration — 0.1.0-prototype.2

Rotated U1 and its decoupling/crystal cluster 90 degrees so USB exits toward the connector. Moved/rotated U5, relocated U9/C25 and R8 for clearer reset/power routing. Connectivity and BOM are unchanged. Netlist, pin specification, source, schematic placement and PCB placement were rechecked with routing disabled; placement has zero errors/warnings, and only the previously accepted generic pin/F1 style warnings remain. The unrouted build and board invariants pass; PCB placement overview was visually inspected.

Fresh native routing still fails: 199 emitted PCB errors, 24 shorts findings and 14 independent drill-to-pad violations. No result is accepted for fabrication. Checks and generated candidates are preserved locally as evidence/iteration-2-*. Tests and formatting/typecheck remain enabled. This placement revision is saved to both repositories to preserve the experiment before the next component moves.

## Placement iteration — 0.1.0-prototype.3

Moved signal/debug test pads toward their associated circuitry, reducing repeated cross-board branches. Unrouted placement/build/invariants pass and the placement overview was inspected. Native routed build now reports zero PCB errors; shorts test reports none; independent drill-to-pad audit passes (minimum 0.154998 mm), 0.5 mm copper-edge margin and 4.010594 mm mounting clearance. All traces are at least 0.15 mm; 173 vias are 0.3/0.6 mm. Format/typecheck and native firmware tests pass. Snapshots generated and reviewed but are NOT accepted due to the connectivity finding below.

A deeper layer-aware copper union audit checks all 57 nets and 273 required ports. It found one open net, VBUS_SENSE: source_net_36_mst2_0 terminates on bottom at U1 GPIO26_ADC0, whose pad is on top, without a via there. Native DRC did not report it. Therefore routing is still rejected. The new scripts/check-copper-connectivity.py reproduces this failure and is now part of the test command. Geometric pad handling is shared with the existing dimensional audit in scripts/copper_geometry.py. No check was weakened. The next placement iteration will move R24/R25/C19 toward U1's ADC pin.

Reviewed local views: iteration-3-top/bottom-detail.png, top/bottom-mcu.png, top/bottom-power.png and schematic.png; local logs are iteration-3-*. Minor silkscreen label overlaps around testpoints/reference text remain a fabrication-review task. Raw snapshots remain local until their full acceptance gate passes.

## Placement iteration — 0.1.0-prototype.4

Moved R24, R25 and C19 above U1 to shorten the ADC input route. This closes VBUS_SENSE but other routed copper violations recur.

Unrouted placement/build/invariants pass and the placement overview was inspected. Routing results: 188 native PCB errors; 34 shorts findings; 15 drill-to-pad violations; disconnected nets: []. This routing candidate is rejected. No manufacturing rule was weakened. Logs: local evidence/iteration-4-*. Generated geometry and audits are preserved in evidence/routing-prototype-4/.

## Placement iteration — 0.1.0-prototype.5

Tightened R24/R25/C19 spacing above the MCU; native DRC reports zero errors, but separate shorts/geometry/connectivity checks still fail, including the ADC bottom-layer endpoint.

Unrouted placement/build/invariants pass and the placement overview was inspected. Routing results: 0 native PCB errors; 20 shorts findings; 3 drill-to-pad violations; disconnected nets: ['VBUS_SENSE']. This routing candidate is rejected. No manufacturing rule was weakened. Logs: local evidence/iteration-5-*. Generated geometry and audits are preserved in evidence/routing-prototype-5/.
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

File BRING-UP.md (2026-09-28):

# Physical bring-up checklist — revision A0

**Pending. No physical board exists or has been tested.** Only perform these checks after design and fabrication gates pass. Record board serial/revision, assembly substitutions, firmware hash, instruments, driver label/revision, motor, supply, DIP settings and ambient conditions for each result.

- Inspect assembly orientation, solder bridges, exposed-pad joints, USB shell anchors and mounting clearances.
- Check unpowered rail resistance and absence of USB backfeeding.
- Power from a current-limited USB source; measure VBUS, 3.3 V, 1.1 V, current and regulator temperature.
- Measure current before enumeration (<100 mA), after configuration (<500 mA), inrush, and USB suspend (<2.5 mA); verify suspend entry/resume and both current-limit startup stages.
- Measure VDRV at each loaded driver pair over USB voltage/cable/temperature corners: require 4.5–5 V, allocated ripple ≤50 mV peak-to-peak, each cable loop ≤1 Ω. Verify short/overload limiting and firmware latch; only USB unmount/reset clears it.
- Confirm normal USB enumeration, both USB-C orientations, reset, BOOTSEL flash recovery and SWD access.
- With the motor supply isolated, scope STEP/DIR/ENA across startup, reset, bootloader, firmware crash/watchdog and USB cable removal. Record pulse widths, edge rates, startup glitches and minimum voltage at driver terminals.
- Connect only the selected DM542T V4.0 with S2 at 5 V and correct motor current settings. Verify ENABLE polarity and its controller-power-loss behavior.
- Verify positive/negative relative movement, configured speed/acceleration, STOP, invalid commands and pulse-count position reports.
- Test each limit using closed contact, open contact, disconnected wire, contact bounce and attempted travel toward/away from the limit.
- Exercise homing from both sides of the switch, already-active input, stuck switch, broken wire, opposite-limit activation, travel bound and timeout.
- Test host closure, unplug, USB suspend, missing heartbeat and reconnect. Record stopping latency and require explicit re-enable.
- Run the intended load over its operating range; measure rail current, temperatures and signal timing. Determine tested limits from measurements rather than design targets.
- Archive scope captures, setup photos, firmware/build identity and pass/fail results. Keep unresolved findings visible in VALIDATION.md.

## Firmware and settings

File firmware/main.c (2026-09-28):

#include <inttypes.h>
#include <stdio.h>
#include <string.h>
#include "pico/stdlib.h"
#include "hardware/adc.h"
#include "hardware/clocks.h"
#include "hardware/pio.h"
#include "hardware/sync.h"
#include "hardware/watchdog.h"
#include "motion.h"
#include "step.pio.h"
#include "tusb.h"
#include "usb_sleep.h"
#include "power_policy.h"

#define STEP_PIN 0
#define DIR_PIN 1
#define ENABLE_PIN 2
#define ARM_PIN 3
#define MIN_PIN 4
#define MAX_PIN 5
#define LED_PIN 25
#define SENSE_PIN 26
#define DRIVER_POWER_PIN 6
#define DRIVER_REG_ENABLE_PIN 7
#define DRIVER_FAULT_PIN 8
static PowerPolicy power;
static Motion motion;
static volatile bool host_connected;
static volatile bool supply_ok;
static PIO step_pio=pio0;
static uint step_sm;
static uint64_t previous_tick;
static void usb_abort(const char *reason) {
    uint32_t irq=save_and_disable_interrupts();
    gpio_put(ARM_PIN,0);
    motion_abort(&motion,reason);
    host_connected=false;
    gpio_put(ENABLE_PIN,0);
    restore_interrupts(irq);
}
void tud_suspend_cb(bool remote_wakeup_enabled) {
    (void)remote_wakeup_enabled;
    usb_abort("usb_suspend");
    gpio_put(DRIVER_REG_ENABLE_PIN,0);
    gpio_put(DRIVER_POWER_PIN,0);
    power=(PowerPolicy){.fault_latched=power.fault_latched};
}
void tud_umount_cb(void) {
    usb_abort("usb_reset");
    gpio_put(DRIVER_REG_ENABLE_PIN,0);
    gpio_put(DRIVER_POWER_PIN,0);
    power=(PowerPolicy){0};
}
void tud_cdc_line_state_cb(uint8_t interface, bool dtr, bool rts) {
    (void)rts;
    if (interface==0 && !dtr) usb_abort("serial_closed");
}
static bool tick(struct repeating_timer *timer) {
    (void)timer;
    uint64_t now=time_us_64();
    if (previous_tick && (now-previous_tick<90 || now-previous_tick>150)) motion_abort(&motion,"timer_overrun");
    previous_tick=now;
    // FIFO must be empty before another pulse is counted/queued.
    if (!pio_sm_is_tx_fifo_empty(step_pio,step_sm)) motion_abort(&motion,"pulse_engine_busy");
    motion_tick(&motion,(MotionInputs){host_connected,supply_ok,gpio_get(MIN_PIN),gpio_get(MAX_PIN)});
    if (motion.enabled && motion.enable_ticks>=2000) gpio_put(DIR_PIN,motion.direction>0);
    gpio_put(ENABLE_PIN,motion.enabled);
    gpio_put(ARM_PIN,motion.enabled);
    gpio_put(LED_PIN,motion.enabled);
    if (motion.pulse) pio_sm_put(step_pio,step_sm,0);
    return true;
}
static void print_status(Motion snapshot) {
    printf("STATUS position=%" PRId64 " enabled=%d homed=%d mode=%d min=%d max=%d supply_ok=%d fault=%s\n",snapshot.position,snapshot.enabled,snapshot.homed,snapshot.mode,snapshot.inputs.minimum,snapshot.inputs.maximum,snapshot.inputs.supply_ok,snapshot.fault);
}
int main(void) {
    for (uint pin=0;pin<=3;pin++) { gpio_init(pin); gpio_put(pin,0); gpio_set_dir(pin,GPIO_OUT); }
    gpio_init(DRIVER_POWER_PIN); gpio_put(DRIVER_POWER_PIN,0); gpio_set_dir(DRIVER_POWER_PIN,GPIO_OUT);
    gpio_init(DRIVER_REG_ENABLE_PIN); gpio_put(DRIVER_REG_ENABLE_PIN,0); gpio_set_dir(DRIVER_REG_ENABLE_PIN,GPIO_OUT);
    gpio_init(DRIVER_FAULT_PIN); gpio_set_dir(DRIVER_FAULT_PIN,GPIO_IN);
    gpio_init(LED_PIN); gpio_set_dir(LED_PIN,GPIO_OUT);
    gpio_init(MIN_PIN); gpio_set_dir(MIN_PIN,GPIO_IN); gpio_set_input_hysteresis_enabled(MIN_PIN,true);
    gpio_init(MAX_PIN); gpio_set_dir(MAX_PIN,GPIO_IN); gpio_set_input_hysteresis_enabled(MAX_PIN,true);
    set_sys_clock_48mhz();
    stdio_init_all();
    adc_init(); adc_gpio_init(SENSE_PIN); adc_select_input(0);
    motion_init(&motion);
    step_sm=pio_claim_unused_sm(step_pio,true);
    uint offset=pio_add_program(step_pio,&step_pulse_program);
    pio_sm_config config=step_pulse_program_get_default_config(offset);
    sm_config_set_set_pins(&config,STEP_PIN,1);
    sm_config_set_clkdiv(&config,48.0f); // 48 MHz / 48: exactly 1 us per PIO cycle.
    pio_gpio_init(step_pio,STEP_PIN);
    pio_sm_set_consecutive_pindirs(step_pio,step_sm,STEP_PIN,1,true);
    pio_sm_init(step_pio,step_sm,offset,&config);
    pio_sm_set_pins_with_mask(step_pio,step_sm,0,1u<<STEP_PIN);
    pio_sm_set_enabled(step_pio,step_sm,true);
    struct repeating_timer timer;
    if (!add_repeating_timer_us(-100,tick,NULL,&timer)) panic("motion timer unavailable");
    watchdog_enable(250,true);
    char line[80]; size_t length=0; bool overflow=false;
    while (true) {
        tud_task_ext(0,false);
        if (tud_suspended()) {
            uint32_t irq=save_and_disable_interrupts();
            // Break the series STEP path before stopping or clearing PIO.
            gpio_put(ARM_PIN,0);
            motion_abort(&motion,"usb_suspend");
            host_connected=false;
            supply_ok=false;
            cancel_repeating_timer(&timer);
            pio_sm_set_enabled(step_pio,step_sm,false);
            pio_sm_clear_fifos(step_pio,step_sm);
            pio_sm_restart(step_pio,step_sm);
            pio_sm_set_pins_with_mask(step_pio,step_sm,0,1u<<STEP_PIN);
            gpio_put(DIR_PIN,0);
            gpio_put(LED_PIN,0);
            // Remove the optocoupler supply. No driver current is taken from
            // USB in suspend. ENA release can restore holding torque.
            gpio_put(ENABLE_PIN,0);
            gpio_put(DRIVER_REG_ENABLE_PIN,0);
            gpio_put(DRIVER_POWER_PIN,0);
            power=(PowerPolicy){.fault_latched=power.fault_latched};
            watchdog_disable();
            adc_run(false);
            adc_hw->cs &= ~ADC_CS_EN_BITS;
            restore_interrupts(irq);
            length=0; overflow=false;
            usb_sleep_until_resume();
            tud_cdc_read_flush();
            gpio_put(ENABLE_PIN,0);
            adc_init(); adc_select_input(0);
            // Reinitialize PC as well as FIFO: no pre-suspend pulse survives.
            pio_sm_init(step_pio,step_sm,offset,&config);
            pio_sm_set_pins_with_mask(step_pio,step_sm,0,1u<<STEP_PIN);
            pio_sm_set_enabled(step_pio,step_sm,true);
            previous_tick=0;
            if (!add_repeating_timer_us(-100,tick,NULL,&timer)) panic("motion timer unavailable");
            watchdog_enable(250,true);
            continue;
        }
        watchdog_update();
        host_connected=stdio_usb_connected();
        // The buck-boost regulates VDRV; this ADC monitors its upstream V5.
        // This is a coarse cable/supply fault threshold, not a voltage reference.
        bool upstream_ok=adc_read()>=2600; // approximately 4.19 V nominal.
        power_policy_update(&power,(PowerInputs){tud_mounted(),false,upstream_ok,!gpio_get(DRIVER_FAULT_PIN),to_ms_since_boot(get_absolute_time())});
        if (power.fault_latched) usb_abort("driver_overcurrent");
        // On shutdown remove regulator enable before its input supply.
        if (!power.regulator_on) gpio_put(DRIVER_REG_ENABLE_PIN,0);
        gpio_put(DRIVER_POWER_PIN,power.switch_on);
        if (power.regulator_on) gpio_put(DRIVER_REG_ENABLE_PIN,1);
        supply_ok=power.ready;
        if (!host_connected) { length=0; overflow=false; }
        int ch=getchar_timeout_us(0);
        if (ch==PICO_ERROR_TIMEOUT) { tight_loop_contents(); continue; }
        if (ch=='\r') continue;
        if (ch=='\n') {
            uint32_t irq=save_and_disable_interrupts();
            const char *reply;
            if (overflow) { motion_abort(&motion,"line_overflow"); reply="ERR line_too_long"; }
            else { line[length]='\0'; reply=motion_command(&motion,line); }
            Motion snapshot=motion;
            restore_interrupts(irq);
            if (!strcmp(reply,"STATUS")) print_status(snapshot); else puts(reply);
            length=0; overflow=false;
        } else if (ch<32 || ch>126 || length>=sizeof(line)-1) overflow=true;
        else if (!overflow) line[length++]=(char)ch;
    }
}

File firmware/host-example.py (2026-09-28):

"""Prototype exercise: explicit --steps authorizes movement. Requires pyserial==3.5."""
import argparse
import time
import serial

parser = argparse.ArgumentParser(description=__doc__)
parser.add_argument("port", help="USB serial device, e.g. /dev/cu.usbmodem...")
parser.add_argument("--steps", type=int, required=True)
args = parser.parse_args()
if not -1000000 <= args.steps <= 1000000:
    parser.error("steps must be between -1000000 and 1000000")
with serial.Serial(args.port, 115200, timeout=1, write_timeout=1) as port:
    port.dtr = True
    time.sleep(0.3)
    port.reset_input_buffer()

    def command(line):
        port.write((line + "\n").encode("ascii"))
        reply = port.readline().decode("ascii").strip()
        if not reply or reply.startswith("ERR"):
            raise RuntimeError(f"{line}: {reply or 'no reply'}")
        return reply

    try:
        print(command("STATUS"))
        command("SPEED 500")
        command("ACCEL 1000")
        command("ENABLE")
        time.sleep(0.25)
        command(f"MOVE {args.steps}")
        deadline = time.monotonic() + abs(args.steps) / 500 + 10
        while True:
            command("PING")
            status = command("STATUS")
            print(status)
            fields = dict(field.split("=", 1) for field in status.split()[1:])
            if fields["fault"] != "none":
                raise RuntimeError(status)
            if fields["mode"] == "0":
                break
            if time.monotonic() > deadline:
                raise RuntimeError("Move did not complete before host timeout")
            time.sleep(0.2)
    finally:
        print(command("STOP"))

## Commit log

2026-09-28 feat: add A0 RP2040 DM542T controller prototype sources
    [bom.csv]
2026-09-28 pcb: rotate MCU cluster and relocate reset circuitry for routing
2026-09-28 pcb: relocate test pads and detect layer-disconnected routes
2026-09-28 pcb: move supply-sense network above MCU
2026-09-28 pcb: tighten supply monitor placement and record failed copper audits
2026-09-28 pcb: investigate guided ADC routing and audit physical shorts
2026-09-28 Adjust ADC filter placement; record remaining open connection
2026-09-28 Route ADC explicitly and record rejected copper candidate
2026-09-28 Move ADC filter beside MCU; preserve failed copper audit
2026-09-28 Achieve clean routing after flash and capacitor placement changes
2026-09-29 Review clean routing, improve silkscreen and export prototype manufacturing files
    [B_Cu.gbr, B_Mask.gbr, B_Paste.gbr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]
2026-09-29 fix: validate stencil and readable legend in A0 prototype.12
    [B_Cu.gbr, B_Mask.gbr, B_Paste.gbr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]
2026-09-29 docs: prepare annotated schematic review for A0 prototype.13
    [B_Cu.gbr, B_Mask.gbr, B_Paste.gbr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]
2026-09-29 fix: audit via clearances and record rejected four-layer prototype.14
2026-09-29 Add evaluation notice to bottom silkscreen
2026-09-29 Add eight A4 schematic sheets and preserve rejected routing investigation
2026-10-01 Record USB-PD stepper reference and blocking JLCPCB import audit

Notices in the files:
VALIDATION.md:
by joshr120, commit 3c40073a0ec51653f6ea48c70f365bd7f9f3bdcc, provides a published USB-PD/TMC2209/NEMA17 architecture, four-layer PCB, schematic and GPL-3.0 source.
